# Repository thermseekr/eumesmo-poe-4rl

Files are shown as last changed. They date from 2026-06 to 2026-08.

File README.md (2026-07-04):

# eumesmo-poe-4rl
PoE powered ESP32 based board featuring 4 SPST NO relays. Ideal for access control, doors, isolated zones or for installing anywhere you need to click dry contacts near some equipment or appliance.

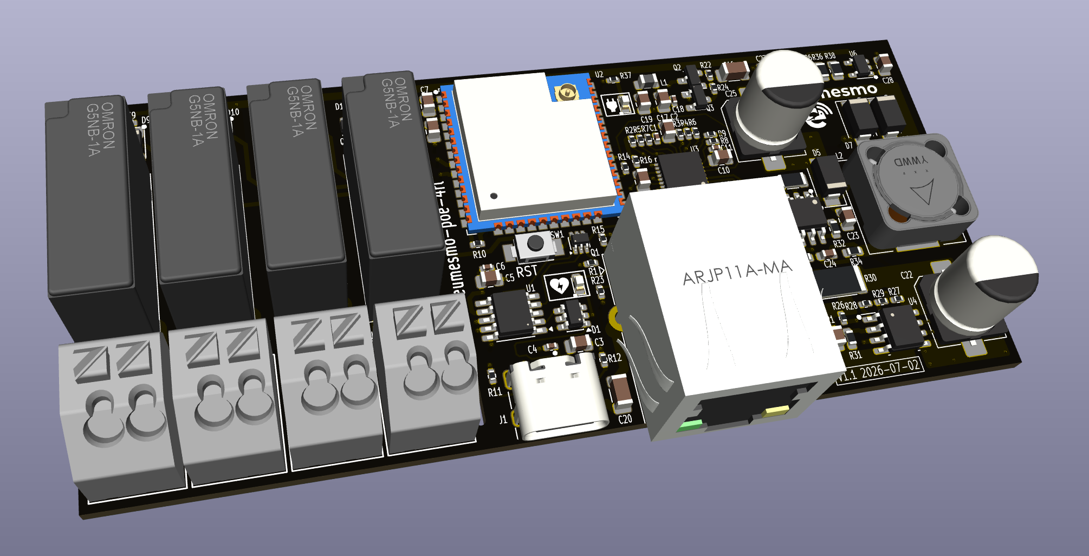
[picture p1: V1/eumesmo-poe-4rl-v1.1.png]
eumesmo-poe-4rl


## VERSION HISTORY

V1.1 - 2026/07/02 - Added CPU health LED.

V1.0 - 2026/06/16 - Initial release.

## LICENSE

This project is licensed under the [Creative Commons BY-NC 4.0 License](https://creativecommons.org/licenses/by-nc/4.0/).
Commercial use is not permitted without prior written consent. See the [LICENSE.txt](LICENSE.txt) file for details.

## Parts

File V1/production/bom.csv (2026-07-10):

Designator | Footprint | Quantity | Value | LCSC Part #
C1, C12, C15, C18, C4, C6, C8, C9 | 0402 | 8 | 100nF/50V | C307331
C10, C13, C3 | 0805 | 3 | 1uF/50V | C28323
C11 | 0402 | 1 | 470pF/50V | C1537
C14, C17, C19, C2, C28, C5, C7 | 0805 | 7 | 10uF/25V | C15850
C16, C27 | 1206 | 2 | 22uF/10V | C5672
C20 | 1206 | 1 | 1nF/2kV | C9196
C21, C23 | 0805 | 2 | 100nF/100V | C28233
C22 | CP_Elec_8x10.5 | 1 | 22uF/100V | C178570
C24 | 0603 | 1 | 12pF/50V | C38523
C25 | CP_Elec_8x10.5 | 1 | 470uF/16V | C96179
C26 | 0402 | 1 | 22pF/50V | C1555
D1 | SOT-23-6 | 1 | USBLC6-2SC6 | C7519
D10, D13, D14, D9 | D_SOD-123 | 4 | 1N4148 | C81598
D11, D12, D15, D16, D3, D8 | 0603 | 6 | WHITE/0603 | C2290
D2 | SOT-23-5 | 1 | ESDS314DBV | C1847859
D4 | D_SMA | 1 | SMAJ58A | C132936
D5 | D_SMA | 1 | SS510 | C65010
D6, D7 | D_SMA | 2 | SS34 | C8678
J1 | USB_C_Receptacle_GCT_USB4105-xx-A_16P_TopMnt_Horizontal | 1 | USB_C_Receptacle_USB2.0 | C2765186
J2 | RJ45_HanRun_HY931147C | 1 | RJ45 JACK | C91754
J3, J4, J5, J6 | TerminalBlock_Wago_250-202_1x02_P3.5mm_45Degree | 4 | 250-202 | C2765061
K1, K2, K3, K4 | Relay_SPST_Omron_G5NB-1A | 4 | G5NB-1A-E-DC5 | C48746
L1 | 0805 | 1 | 2A/600R | C139168
L2 | L_12x12mm_H6mm | 1 | 33uH/2,1A | C169386
L3 | L_3x3mm_H1.5mm | 1 | 2,2uH/1,5A | C370424
Q1 | SOT-363_SC-70-6 | 1 | UMH3N | C62892
Q2 | SOT-23 | 1 | WPM2015-3/TR | C558305
Q3 | SOT-23 | 1 | LMUN2211LT1G | C150229
Q4, Q5, Q6, Q7 | SOT-23 | 4 | MMBT2222A | C8512
R1, R10, R13, R16, R22, R29, R43, R44, R49, R50 | 0402 | 10 | 10k | C25744
R11, R12 | 0402 | 2 | 5,1k | C105872
R14 | 0402 | 1 | 33R | C25105
R15, R23, R25, R37 | 0402 | 4 | 330R | C25104
R17, R19, R20, R21 | 0402 | 4 | 49,9R | C25120
R18 | 0402 | 1 | 12,1k | C25852
R2 | 0402 | 1 | 1.5k | C25867
R24, R39, R40, R41, R42, R45, R46, R47, R48 | 0402 | 9 | 1k | C11702
R26 | 0402 | 1 | 30,1k | C138009
R27 | 0402 | 1 | 130k | C93946
R28 | 0402 | 1 | 180k | C138046
R3, R4, R5, R6, R7, R8, R9 | 0402 | 7 | 2.2k | C25879
R30 | 2512 | 1 | 4,7k/1W | C878291
R31 | 0603 | 1 | 4,42k/100mW | C482858
R32 | 0603 | 1 | 5,1R/100mW | C25197
R33 | 1206 | 1 | 30mR/250mW | C473665
R34 | 0603 | 1 | 300k/100mW | C23024
R35 | 0603 | 1 | 52,3k/100mW | C23198
R36 | 0805 | 1 | 100k/0,125W | C149504
R38 | 0805 | 1 | 22,1k/0,125W | C17552
SW1 | SW_SPST_Xunpu_TS1088AR02016 | 1 | RESET | C720477
U1 | SSOP-10-1EP_3.9x4.9mm_P1mm_EP2.1x3.3mm | 1 | CH340K | C968586
U2 | ESP32-WROOM-32U | 1 | ESP32-WROOM-32UE-N16 | C701346
U3 | QFN-32-1EP_5x5mm_P0.5mm_EP3.3x3.3mm_ThermalVias | 1 | LAN8710A | C46185
U4 | SOIC-8-1EP_3.9x4.9mm_P1.27mm_EP2.95x4.9mm_Mask2.71x3.4mm_ThermalVias | 1 | TPS2376DDAR-H | C544899
U5 | SOIC-8-1EP_3.9x4.9mm_P1.27mm_EP2.41x3.81mm_ThermalVias | 1 | TX4138 | C329267
U6 | SOT-23-5_Shorter_Pins | 1 | SY8089A1AAC | C479074

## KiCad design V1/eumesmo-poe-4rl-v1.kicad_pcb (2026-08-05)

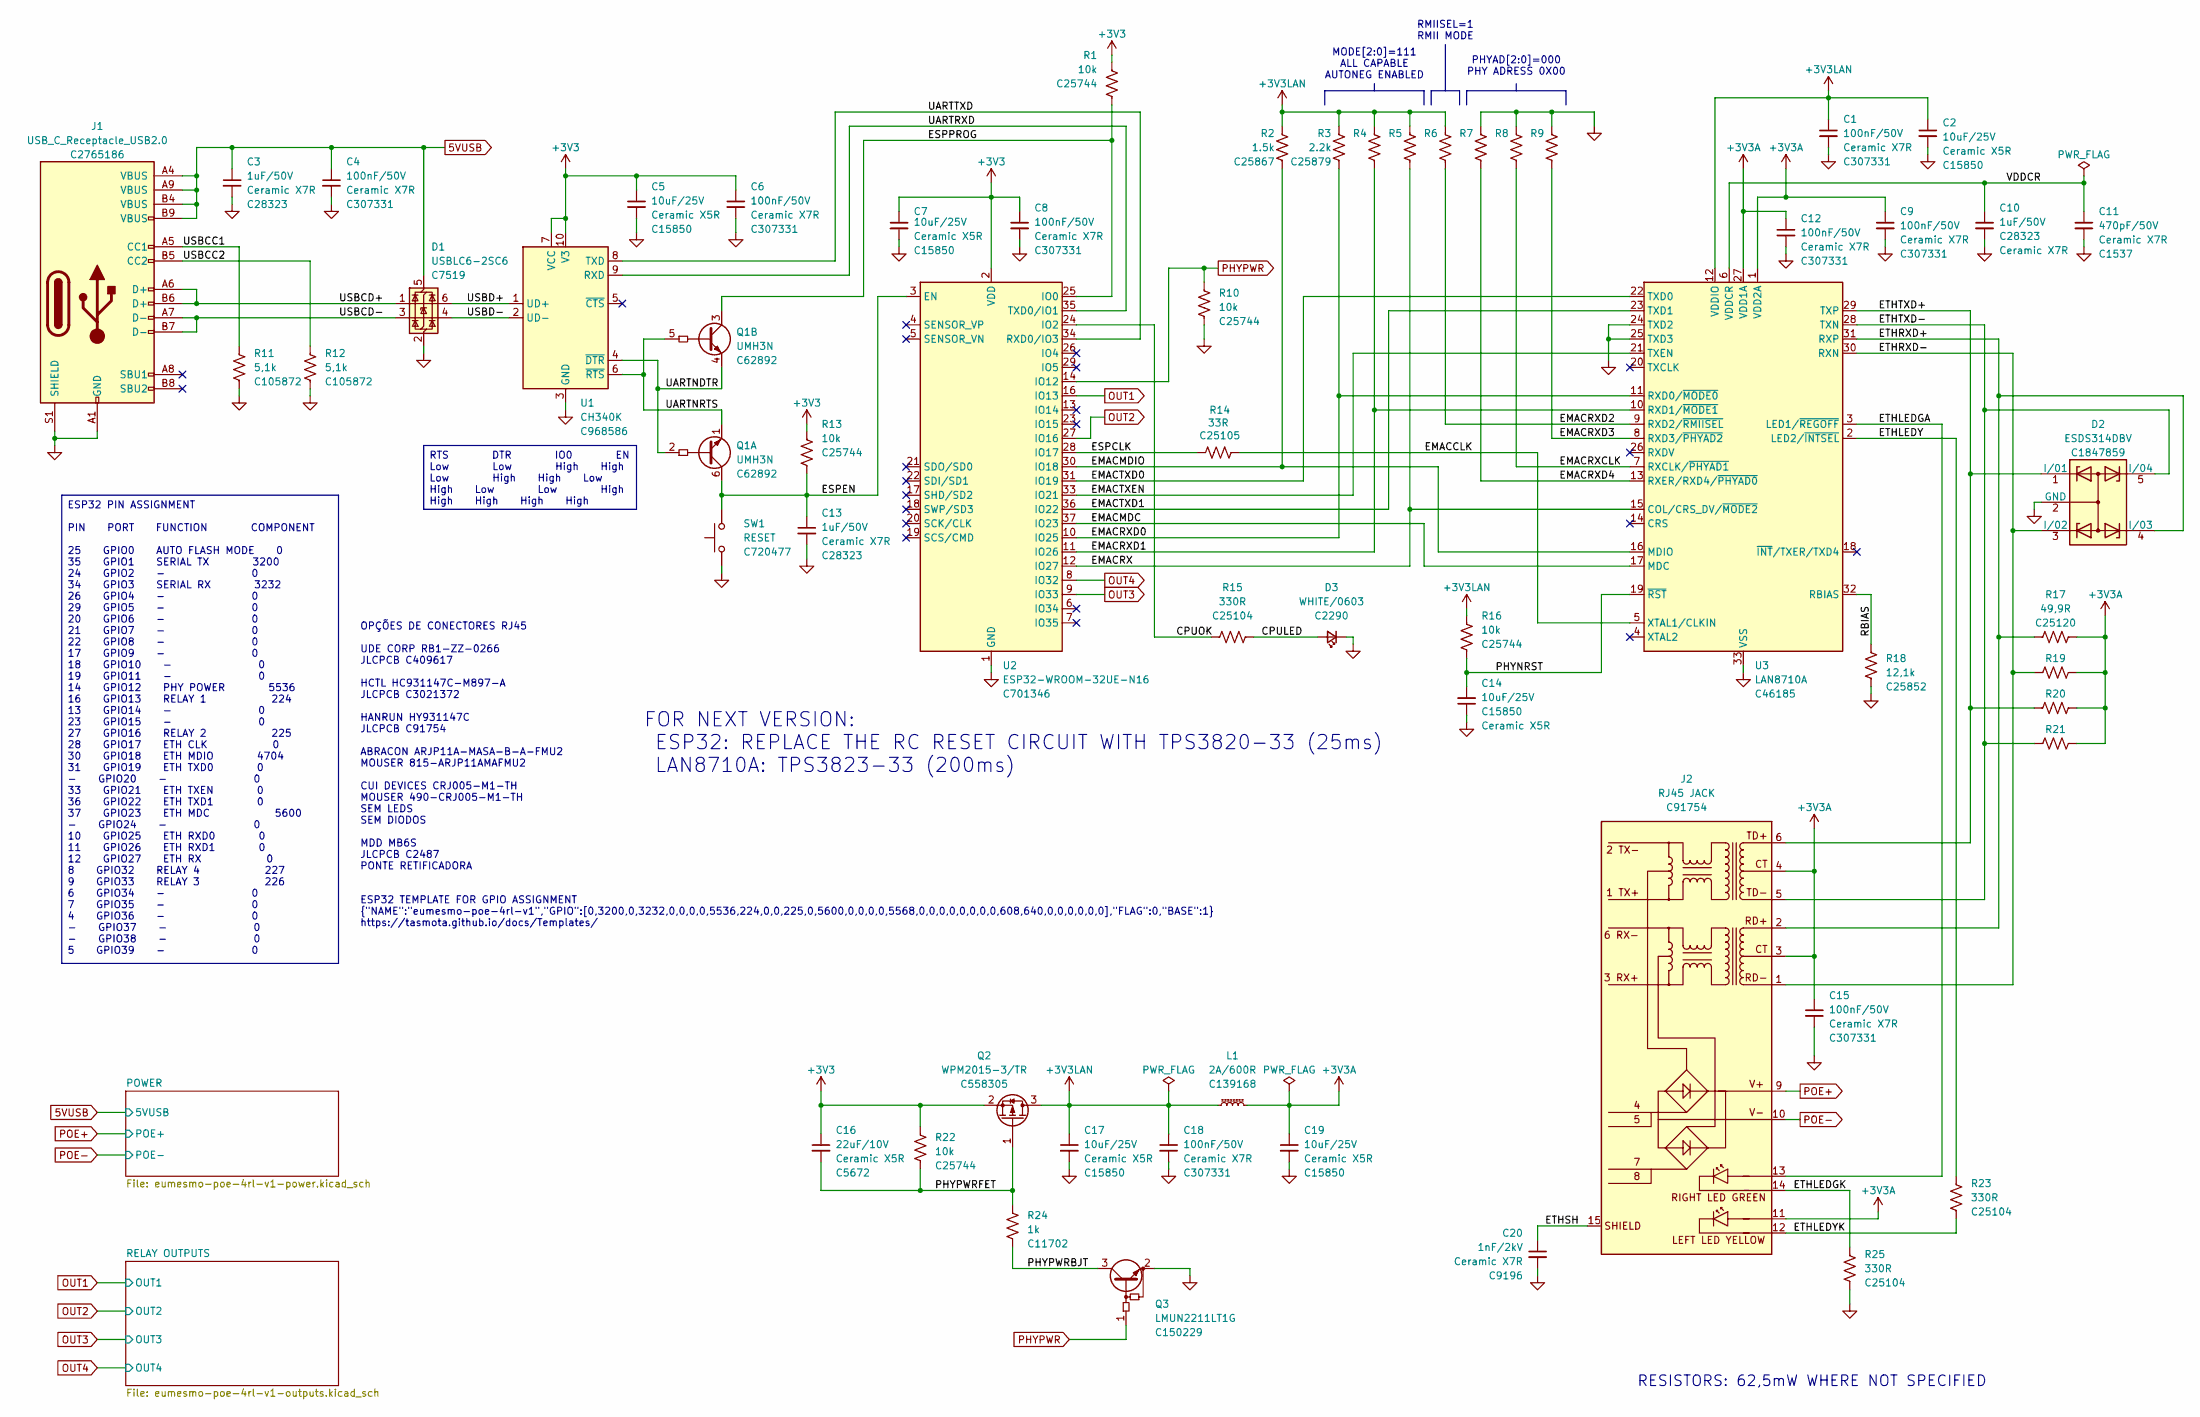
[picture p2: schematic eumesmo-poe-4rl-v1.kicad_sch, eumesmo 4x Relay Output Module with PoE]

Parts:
C1, C4, C6, C8, C9, C12, C15, C18: 100nF/50V; C_0402_1005Metric; Mfr PN CL05B104KB54PNC; JLCPCB BOM 1
C2, C7, C14, C17, C19: 10uF/25V; C_0805_2012Metric; Mfr PN CL21A106KAYNNNE; JLCPCB BOM 1
C3, C10, C13: 1uF/50V; C_0805_2012Metric; Mfr PN CL21B105KBFNNNE; JLCPCB BOM 1
C5: 10uF/25V; C_0805_2012Metric; Mfr PN CL21A106KAYNNNE; LCSC Part # C15850
C11: 470pF/50V; C_0402_1005Metric; Mfr PN 0402B471K500NT; JLCPCB BOM 1
C16: 22uF/10V; C_1206_3216Metric; Mfr PN CL31A226KPHNNNE; JLCPCB BOM 1
C20: 1nF/2kV; C_1206_3216Metric; Mfr PN 1206B102K202NT; JLCPCB BOM 1
D1: USBLC6-2SC6; SOT-23-6; Mfr PN USBLC6-2SC6; JLCPCB BOM 1
D2: ESDS314DBV; SOT-23-5; Mfr PN ESDS314DBVR; JLCPCB BOM 1
D3: WHITE/0603; LED_0603_1608Metric; Mfr PN KT-0603W; LCSC Part # C2290
J1: USB_C_Receptacle_USB2.0; USB_C_Receptacle_GCT_USB4105-xx-A_16P_TopMnt_Horizontal; Mfr PN TYPE-C 16PIN 2MD(073); JLCPCB BOM 1
J2: RJ45 JACK; RJ45_HanRun_HY931147C; Mfr PN HY931147C; JLCPCB BOM 1
L1: 2A/600R; L_0805_2012Metric; Mfr PN CBM201209U601T; JLCPCB BOM 1
Q1: UMH3N; SOT-363_SC-70-6; Mfr PN UMH3N; JLCPCB BOM 1
Q2: WPM2015-3/TR; SOT-23; Mfr PN WPM2015-3/TR; JLCPCB BOM 1
Q3: LMUN2211LT1G; SOT-23; Mfr PN MMUN2211LT3G; LCSC Part # C150229
R1, R10, R13, R16, R22: 10k; R_0402_1005Metric; Mfr PN 0402WGF1002TCE; LCSC Part # C25744
R2: 1.5k; R_0402_1005Metric; Mfr PN 0402WGF1501TCE; LCSC Part # C25867
R3, R4, R5, R6, R7, R8, R9: 2.2k; R_0402_1005Metric; Mfr PN 0402WGF2201TCE; LCSC Part # C25879
R11, R12: 5,1k; R_0402_1005Metric; Mfr PN RC0402FR-075K1L; JLCPCB BOM 1
R14: 33R; R_0402_1005Metric; Mfr PN 0402WGF330JTCE; JLCPCB BOM 1
R15, R23, R25: 330R; R_0402_1005Metric; Mfr PN 0402WGF3300TCE; LCSC Part # C25104
R17, R19, R20, R21: 49,9R; R_0402_1005Metric; Mfr PN 0402WGF499JTCE; JLCPCB BOM 1
R18: 12,1k; R_0402_1005Metric; Mfr PN 0402WGF1212TCE; JLCPCB BOM 1
R24: 1k; R_0402_1005Metric; Mfr PN 0402WGF1001TCE; LCSC Part # C11702
SW1: RESET; SW_SPST_Xunpu_TS1088AR02016; Mfr PN TS-1088-AR02016; JLCPCB BOM 1
U1: CH340K; SSOP-10-1EP_3.9x4.9mm_P1mm_EP2.1x3.3mm; Mfr PN CH340K; JLCPCB BOM 1
U2: ESP32-WROOM-32UE-N16; ESP32-WROOM-32U; Mfr PN ESP32-WROOM-32UE-N16; JLCPCB BOM 1
U3: LAN8710A; QFN-32-1EP_5x5mm_P0.5mm_EP3.3x3.3mm_ThermalVias; Mfr PN LAN8710A-EZC-TR; JLCPCB BOM 1

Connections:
5VUSB: C3.1, C4.1, D1.5 (VBUS), J1.A4 (VBUS), J1.A9 (VBUS), J1.B4 (VBUS), J1.B9 (VBUS); also elsewhere on the board
+3V3: C5.1, C6.1, C7.1, C8.1, C16.1, Q2.2 (S), R1.1, R13.1, R22.1, U1.7 (VCC), U1.10 (V3), U2.2 (VDD); also elsewhere on the board
+3V3A: C9.1, C12.1, C15.1, C19.1, J2.3 (CT), J2.4 (CT), J2.11 (LLED+), L1.2, R17.2, R19.2, R20.2, R21.2, U3.1 (VDD2A), U3.27 (VDD1A)
+3V3LAN: C1.1, C2.1, C17.1, C18.1, L1.1, Q2.3 (D), R2.1, R3.1, R4.1, R5.1, R6.1, R16.2, U3.12 (VDDIO)
/CPULED: D3.2 (A), R15.2
/CPUOK: R15.1, U2.24 (IO2)
/EMACCLK: R14.2, U3.5 (XTAL1/CLKIN)
/EMACMDC: U2.37 (IO23), U3.17 (MDC)
/EMACMDIO: R2.2, U2.30 (IO18), U3.16 (MDIO)
/EMACRX: R5.2, U2.12 (IO27), U3.15 (COL/CRS_DV/~MODE2)
/EMACRXCLK: R8.2, U3.7 (RXCLK/~PHYAD1)
/EMACRXD0: R3.2, U2.10 (IO25), U3.11 (RXD0/~MODE0)
/EMACRXD1: R4.2, U2.11 (IO26), U3.10 (RXD1/~MODE1)
/EMACRXD2: R6.2, U3.9 (RXD2/~RMIISEL)
/EMACRXD3: R9.2, U3.8 (RXD3/~PHYAD2)
/EMACRXD4: R7.2, U3.13 (RXER/RXD4/~PHYAD0)
/EMACTXD0: U2.31 (IO19), U3.22 (TXD0)
/EMACTXD1: U2.36 (IO22), U3.23 (TXD1)
/EMACTXEN: U2.33 (IO21), U3.21 (TXEN)
/ESPCLK: R14.1, U2.28 (IO17)
/ESPEN: C13.1, Q1.6 (C1), R13.2, SW1.2, U2.3 (EN)
/ESPPROG: Q1.3 (C2), R1.2, U2.25 (IO0)
/ETHLEDGA: J2.13 (RLED+), U3.3 (LED1/~REGOFF)
/ETHLEDGK: J2.14 (RLED-), R25.2
/ETHLEDY: R23.2, U3.2 (LED2/~INTSEL)
/ETHLEDYK: J2.12 (LLED-), R23.1
/ETHRXD+: D2.4 (I/03), J2.2 (RD+), R17.1, U3.31 (RXP)
/ETHRXD-: D2.3 (I/02), J2.1 (RD-), R19.1, U3.30 (RXN)
/ETHSH: C20.1, J2.15 (SHIELD)
/ETHTXD+: D2.1 (I/01), J2.6 (TD+), R20.1, U3.29 (TXP)
/ETHTXD-: D2.5 (I/04), J2.5 (TD-), R21.1, U3.28 (TXN)
/PHYNRST: C14.2, R16.1, U3.19 (~RST)
/PHYPWRBJT: Q3.3 (C), R24.2
/PHYPWRFET: C16.2, Q2.1 (G), R22.2, R24.1
/RBIAS: R18.1, U3.32 (RBIAS)
/UARTNDTR: Q1.2 (B1), Q1.4 (E2), U1.4 (~DTR)
/UARTNRTS: Q1.1 (E1), Q1.5 (B2), U1.6 (~RTS)
/UARTRXD: U1.9 (RXD), U2.35 (TXD0/IO1)
/UARTTXD: U1.8 (TXD), U2.34 (RXD0/IO3)
/USBCC1: J1.A5 (CC1), R11.1
/USBCC2: J1.B5 (CC2), R12.1
/USBCD+: D1.1 (I/O1), J1.A6 (D+), J1.B6 (D+)
/USBCD-: D1.3 (I/O2), J1.A7 (D-), J1.B7 (D-)
/USBD+: D1.6 (I/O1), U1.1 (UD+)
/USBD-: D1.4 (I/O2), U1.2 (UD-)
/VDDCR: C10.1, C11.1, U3.6 (VDDCR)
GND: C1.2, C2.2, C3.2, C4.2, C5.2, C6.2, C7.2, C8.2, C9.2, C10.2, C11.2, C12.2, C13.2, C14.1, C15.2, C17.2, C18.2, C19.2, C20.2, D1.2 (GND), D2.2 (GND), D3.1 (K), J1.A1 (GND), J1.A12 (GND), J1.B1 (GND), J1.B12 (GND), J1.S1 (SHIELD), Q3.2 (E), R7.1, R8.1, R9.1, R10.1, R11.2, R12.2, R18.2, R25.1, SW1.1, U1.3 (GND), U1.11 (GND), U2.1 (GND), U2.15 (GND), U2.38 (GND), U2.39 (GND), U3.24 (TXD2), U3.25 (TXD3), U3.33 (VSS); also elsewhere on the board
OUT1: U2.16 (IO13); also elsewhere on the board
OUT2: U2.27 (IO16); also elsewhere on the board
OUT3: U2.9 (IO33); also elsewhere on the board
OUT4: U2.8 (IO32); also elsewhere on the board
PHYPWR: Q3.1 (B), R10.2, U2.14 (IO12)
POE+: J2.9 (V+); also elsewhere on the board
POE-: J2.10 (V-); also elsewhere on the board

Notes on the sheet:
RMIISEL=1 RMII MODE
PHYAD[2:0]=000 PHY ADRESS 0X00
OPÇÕES DE CONECTORES RJ45 UDE CORP RB1-ZZ-0266 JLCPCB C409617 HCTL HC931147C-M897-A JLCPCB C3021372 HANRUN HY931147C JLCPCB C91754 ABRACON ARJP11A-MASA-B-A-FMU2 MOUSER 815-ARJP11AMAFMU2 CUI DEVICES CRJ005-M1-TH MOUSER 490-CRJ005-M1-TH SEM LEDS SEM DIODOS MDD MB6S JLCPCB C2487 PONTE RETIFICADORA
ESP32 TEMPLATE FOR GPIO ASSIGNMENT {"NAME":"eumesmo-poe-4rl-v1","GPIO":[0,3200,0,3232,0,0,0,0,5536,224,0,0,225,0,5600,0,0,0,0,5568,0,0,0,0,0,0,0,0,608,640,0,0,0,0,0,0],"FLAG":0,"BASE":1} https://tasmota.github.io/docs/Templates/
RESISTORS: 62,5mW WHERE NOT SPECIFIED
MODE[2:0]=111 ALL CAPABLE AUTONEG ENABLED
FOR NEXT VERSION: ESP32: REPLACE THE RC RESET CIRCUIT WITH TPS3820-33 (25ms) LAN8710A: TPS3823-33 (200ms)
ESP32 PIN ASSIGNMENT PIN PORT FUNCTION COMPONENT 25 GPIO0 AUTO FLASH MODE 0 35 GPIO1 SERIAL TX 3200 24 GPIO2 - 0 34 GPIO3 SERIAL RX 3232 26 GPIO4 - 0 29 GPIO5 - 0 20 GPIO6 - 0 21 GPIO7 - 0 22 GPIO8 - 0 17 GPIO9 - 0 18 GPIO10 - 0 19 GPIO11 - 0 14 GPIO12 PHY POWER 5536 16 GPIO13 RELAY 1 224 13 GPIO14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
RTS DTR IO0 EN Low Low High High Low High High Low High Low Low High High High High High

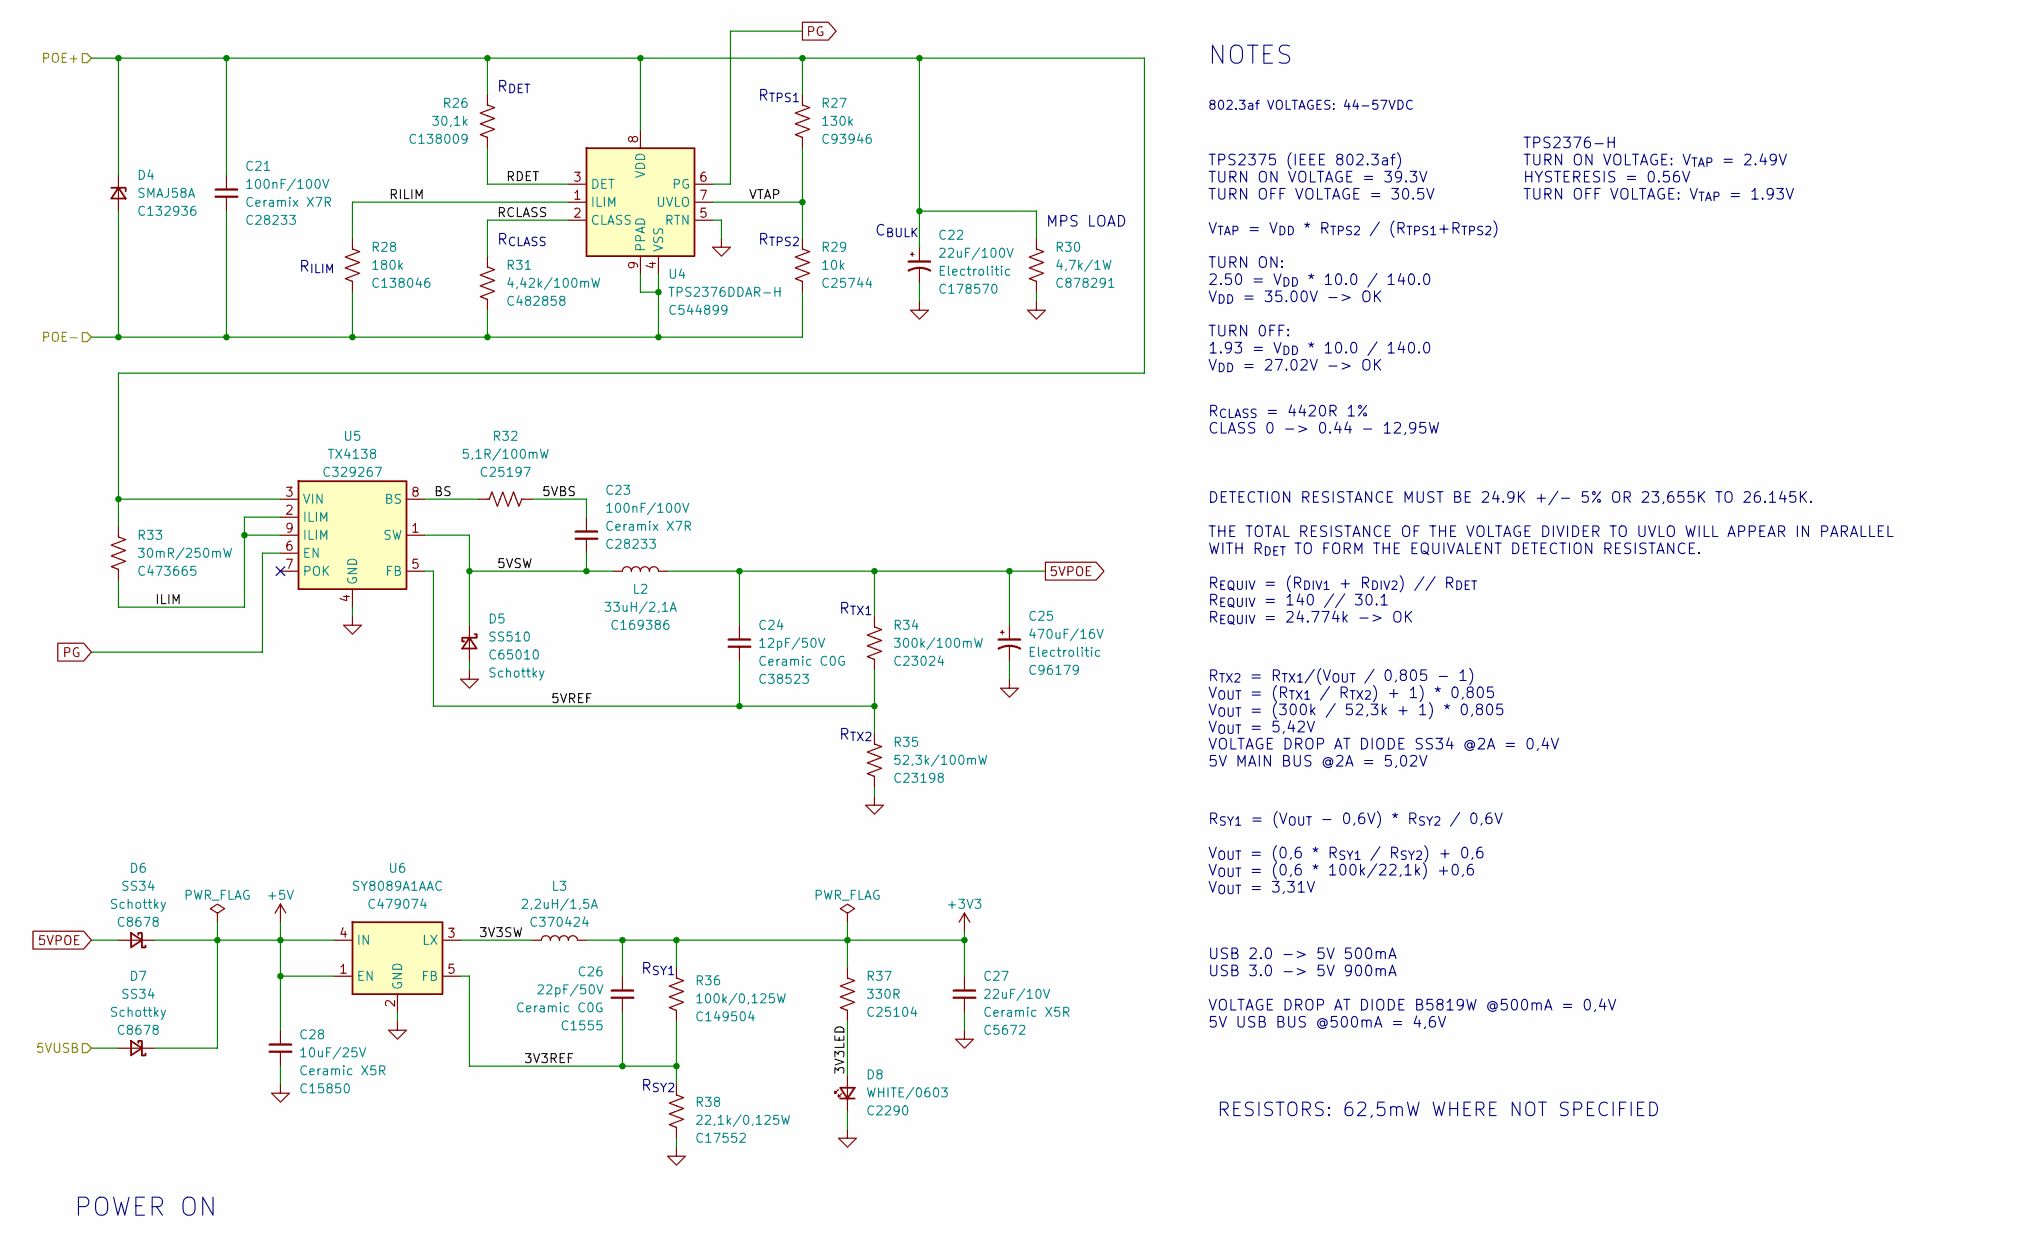
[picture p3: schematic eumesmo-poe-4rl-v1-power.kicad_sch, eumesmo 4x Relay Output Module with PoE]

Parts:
C21: 100nF/100V; C_0805_2012Metric; Mfr PN CL21B104KCFNNNE; JLCPCB BOM 1
C22: 22uF/100V; CP_Elec_8x10.5; Mfr PN EEEFK2A220P; LCSC Part # C178570
C23: 100nF/100V; C_0805_2012Metric; Mfr PN CL21B104KCFNNNE; LCSC Part # C28233
C24: 12pF/50V; C_0603_1608Metric; Mfr PN CL10C120JB8NNNC; JLCPCB BOM 1
C25: 470uF/16V; CP_Elec_8x10.5; Mfr PN CS1C471M-CRF10; JLCPCB BOM 1
C26: 22pF/50V; C_0402_1005Metric; Mfr PN 0402CG220J500NT; JLCPCB BOM 1
C27: 22uF/10V; C_1206_3216Metric; Mfr PN CL31A226KPHNNNE; JLCPCB BOM 1
C28: 10uF/25V; C_0805_2012Metric; Mfr PN CL21A106KAYNNNE; JLCPCB BOM 1
D4: SMAJ58A; D_SMA; Mfr PN SMAJ58A-TR; JLCPCB BOM 1
D5: SS510; D_SMA; Mfr PN SS510; JLCPCB BOM 1
D6, D7: SS34; D_SMA; Mfr PN SS34; JLCPCB BOM 1
D8: WHITE/0603; LED_0603_1608Metric; Mfr PN KT-0603W; LCSC Part # C2290
L2: 33uH/2,1A; L_12x12mm_H6mm; Mfr PN SWRB1205S-330MT; JLCPCB BOM 1
L3: 2,2uH/1,5A; L_3x3mm_H1.5mm; Mfr PN SPH3015H2R2MT; JLCPCB BOM 1
R26: 30,1k; R_0402_1005Metric; Mfr PN RC0402FR-0730K1L; JLCPCB BOM 1
R27: 130k; R_0402_1005Metric; Mfr PN RC0402FR-07130KL; JLCPCB BOM 1
R28: 180k; R_0402_1005Metric; Mfr PN RC0402FR-07180KL; JLCPCB BOM 1
R29: 10k; R_0402_1005Metric; Mfr PN 0402WGF1002TCE; JLCPCB BOM 1
R30: 4,7k/1W; R_2512_6332Metric; Mfr PN RC2512JK-074K7L; JLCPCB BOM 1
R31: 4,42k/100mW; R_0603_1608Metric; Mfr PN RC0603FR-074K42L; JLCPCB BOM 1
R32: 5,1R/100mW; R_0603_1608Metric; Mfr PN 0603WAF510KT5E; LCSC Part # C25197
R33: 30mR/250mW; R_1206_3216Metric; Mfr PN 1206W3F300MT5E; LCSC Part # C473665
R34: 300k/100mW; R_0603_1608Metric; Mfr PN 0603WAF3003T5E; JLCPCB BOM 1
R35: 52,3k/100mW; R_0603_1608Metric; Mfr PN 0603WAF5232T5E; JLCPCB BOM 1
R36: 100k/0,125W; R_0805_2012Metric; Mfr PN 0805W8F1003T5E; JLCPCB BOM 1
R37: 330R; R_0402_1005Metric; Mfr PN 0402WGF3300TCE; LCSC Part # C25104
R38: 22,1k/0,125W; R_0805_2012Metric; Mfr PN 0805W8F2212T5E; JLCPCB BOM 1
U4: TPS2376DDAR-H; SOIC-8-1EP_3.9x4.9mm_P1.27mm_EP2.95x4.9mm_Mask2.71x3.4mm_Th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; Mfr PN TPS2376DDAR-H; JLCPCB BOM 1
U5: TX4138; SOIC-8-1EP_3.9x4.9mm_P1.27mm_EP2.41x3.81mm_ThermalVias; Mfr PN TX4138; JLCPCB BOM 1
U6: SY8089A1AAC; SOT-23-5_Shorter_Pins; Mfr PN SY8089A1AAC; JLCPCB BOM 1

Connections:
5VPOE: C24.1, C25.1, D6.2 (A), L2.2, R34.1
5VUSB: D7.2 (A); also elsewhere on the board
+3V3: C26.1, C27.1, L3.2, R36.1, R37.1; also elsewhere on the board
+5V: C28.1, D6.1 (K), D7.1 (K), U6.1 (EN), U6.4 (IN); also elsewhere on the board
/POWER/3V3LED: D8.2 (A), R37.2
/POWER/3V3REF: C26.2, R36.2, R38.1, U6.5 (FB)
/POWER/3V3SW: L3.1, U6.3 (LX)
/POWER/5VBS: C23.1, R32.1
/POWER/5VREF: C24.2, R34.2, R35.1, U5.5 (FB)
/POWER/5VSW: C23.2, D5.1 (K), L2.1, U5.1 (SW)
/POWER/BS: R32.2, U5.8 (BS)
/POWER/ILIM: R33.2, U5.2 (ILIM), U5.9 (ILIM)
/POWER/RCLASS: R31.1, U4.2 (CLASS)
/POWER/RDET: R26.2, U4.3 (DET)
/POWER/RILIM: R28.1, U4.1 (ILIM)
/POWER/VTAP: R27.2, R29.1, U4.7 (UVLO)
GND: C22.2, C25.2, C27.2, C28.2, D5.2 (A), D8.1 (K), R30.2, R35.2, R38.2, U4.5 (RTN), U5.4 (GND), U6.2 (GND); also elsewhere on the board
PG: U4.6 (PG), U5.6 (EN)
POE+: C21.1, C22.1, D4.1 (K), R26.1, R27.1, R30.1, R33.1, U4.8 (VDD), U5.3 (VIN); also elsewhere on the board
POE-: C21.2, D4.2 (A), R28.2, R29.2, R31.2, U4.4 (VSS), U4.9 (PPAD); also elsewhere on the board

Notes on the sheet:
R_{TPS1}
R_{TX2}
DETECTION RESISTANCE MUST BE 24.9K +/- 5% OR 23,655K TO 26.145K. THE TOTAL RESISTANCE OF THE VOLTAGE DIVIDER TO UVLO WILL APPEAR IN PARALLEL WITH R_{DET} TO FORM THE EQUIVALENT DETECTION RESISTANCE. R_{EQUIV} = (R_{DIV1} + R_{DIV2}) // R_{DET} R_{EQUIV} = 140 // 30.1 R_{EQUIV} = 24.774k -> OK
R_{SY2}
RESISTORS: 62,5mW WHERE NOT SPECIFIED
POWER ON
R_{CLASS} = 4420R 1% CLASS 0 -> 0.44 - 12,95W
R_{SY1}
R_{CLASS}
R_{TX2} = R_{TX1}/(V_{OUT} / 0,805 - 1) V_{OUT} = (R_{TX1} / R_{TX2}) + 1) * 0,805 V_{OUT} = (300k / 52,3k + 1) * 0,805 V_{OUT} = 5,42V VOLTAGE DROP AT DIODE SS34 @2A = 0,4V 5V MAIN BUS @2A = 5,02V
C_{BULK}
R_{ILIM}
USB 2.0 -> 5V 500mA USB 3.0 -> 5V 900mA VOLTAGE DROP AT DIODE B5819W @500mA = 0,4V 5V USB BUS @500mA = 4,6V
TPS2375 (IEEE 802.3af) TURN ON VOLTAGE = 39.3V TURN OFF VOLTAGE = 30.5V
TPS2376-H TURN ON VOLTAGE: V_{TAP} = 2.49V HYSTERESIS = 0.56V TURN OFF VOLTAGE: V_{TAP} = 1.93V
R_{SY1} = (V_{OUT} - 0,6V) * R_{SY2} / 0,6V V_{OUT} = (0,6 * R_{SY1} / R_{SY2}) + 0,6 V_{OUT} = (0,6 * 100k/22,1k) +0,6 V_{OUT} = 3,31V
R_{TPS2}
R_{TX1}
NOTES
MPS LOAD
R_{DET}
802.3af VOLTAGES: 44-57VDC
V_{TAP} = V_{DD} * R_{TPS2} / (R_{TPS1}+R_{TPS2}) TURN ON: 2.50 = V_{DD} * 10.0 / 140.0 V_{DD} = 35.00V -> OK TURN 0FF: 1.93 = V_{DD} * 10.0 / 140.0 V_{DD} = 27.02V -> OK

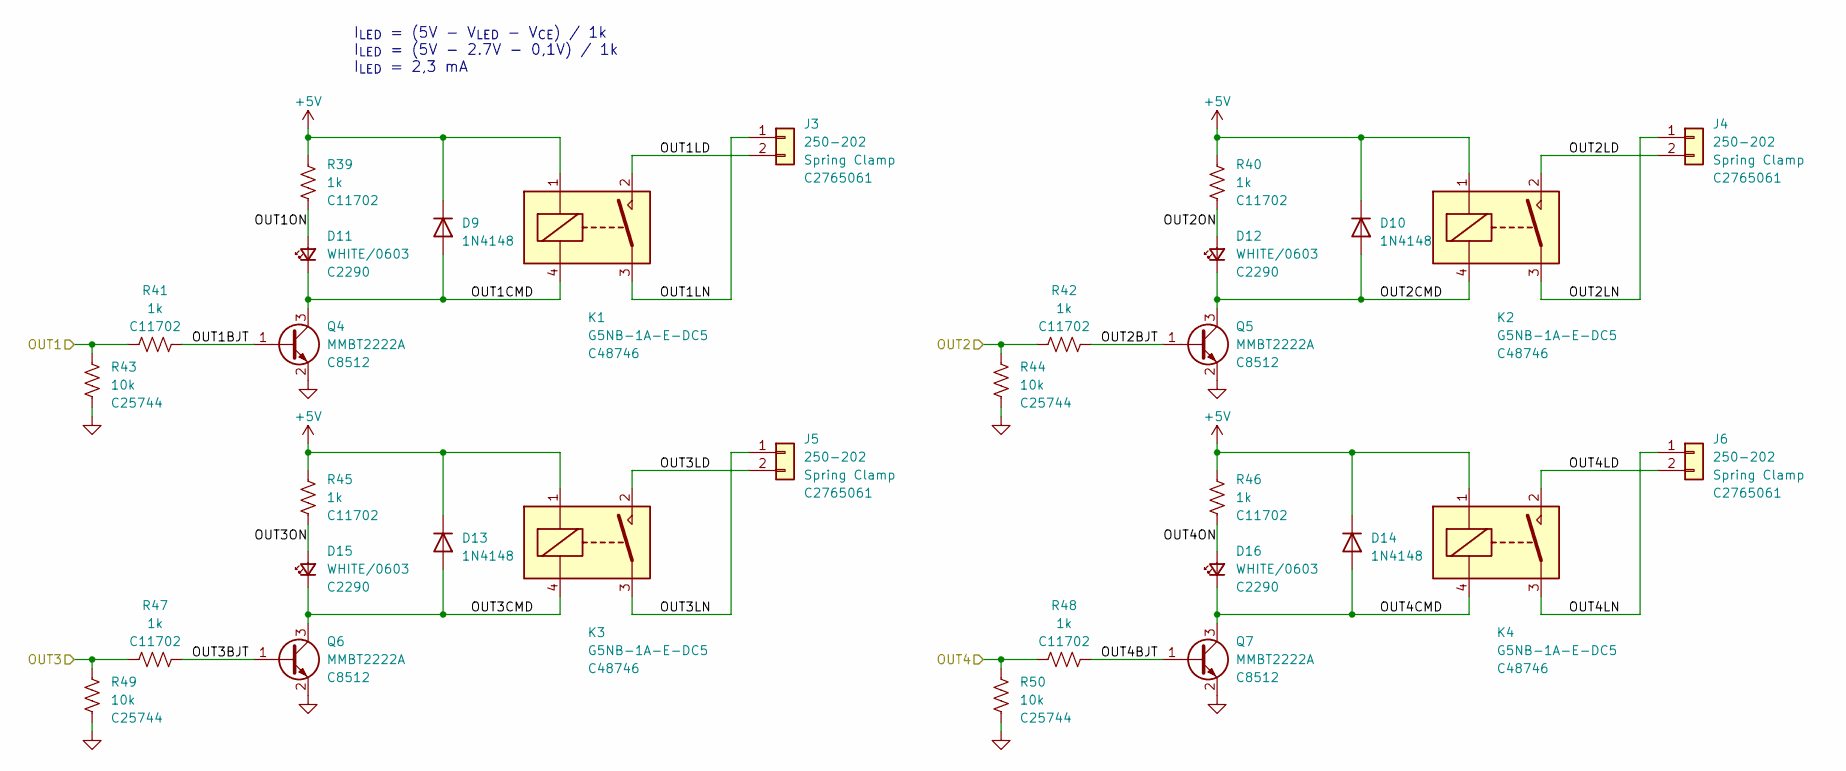
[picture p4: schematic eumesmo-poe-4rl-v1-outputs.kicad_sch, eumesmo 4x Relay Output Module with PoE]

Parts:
D9, D10, D13, D14: 1N4148; D_SOD-123; Mfr PN 1N4148W; JLCPCB BOM 1
D11, D12, D15, D16: WHITE/0603; LED_0603_1608Metric; Mfr PN KT-0603W; LCSC Part # C2290
J3, J4, J5, J6: 250-202; TerminalBlock_Wago_250-202_1x02_P3.5mm_45Degree; Mfr PN 250-202; JLCPCB BOM 1
K1, K2, K3, K4: G5NB-1A-E-DC5; Relay_SPST_Omron_G5NB-1A; Mfr PN G5NB-1A-E-DC5; JLCPCB BOM 1
Q4, Q5, Q6, Q7: MMBT2222A; SOT-23; Mfr PN MMBT2222A; JLCPCB BOM 1
R39, R40, R41, R42, R45, R46, R47, R48: 1k; R_0402_1005Metric; Mfr PN 0402WGF1001TCE; LCSC Part # C11702
R43, R44, R49, R50: 10k; R_0402_1005Metric; Mfr PN 0402WGF1002TCE; LCSC Part # C25744

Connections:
+5V: D9.1 (K), D10.1 (K), D13.1 (K), D14.1 (K), K1.1, K2.1, K3.1, K4.1, R39.1, R40.1, R45.1, R46.1; also elsewhere on the board
/RELAY OUTPUTS/OUT1BJT: Q4.1 (B), R41.1
/RELAY OUTPUTS/OUT1CMD: D9.2 (A), D11.1 (K), K1.4, Q4.3 (C)
/RELAY OUTPUTS/OUT1LD: J3.2, K1.2
/RELAY OUTPUTS/OUT1LN: J3.1, K1.3
/RELAY OUTPUTS/OUT1ON: D11.2 (A), R39.2
/RELAY OUTPUTS/OUT2BJT: Q5.1 (B), R42.1
/RELAY OUTPUTS/OUT2CMD: D10.2 (A), D12.1 (K), K2.4, Q5.3 (C)
/RELAY OUTPUTS/OUT2LD: J4.2, K2.2
/RELAY OUTPUTS/OUT2LN: J4.1, K2.3
/RELAY OUTPUTS/OUT2ON: D12.2 (A), R40.2
/RELAY OUTPUTS/OUT3BJT: Q6.1 (B), R47.1
/RELAY OUTPUTS/OUT3CMD: D13.2 (A), D15.1 (K), K3.4, Q6.3 (C)
/RELAY OUTPUTS/OUT3LD: J5.2, K3.2
/RELAY OUTPUTS/OUT3LN: J5.1, K3.3
/RELAY OUTPUTS/OUT3ON: D15.2 (A), R45.2
/RELAY OUTPUTS/OUT4BJT: Q7.1 (B), R48.1
/RELAY OUTPUTS/OUT4CMD: D14.2 (A), D16.1 (K), K4.4, Q7.3 (C)
/RELAY OUTPUTS/OUT4LD: J6.2, K4.2
/RELAY OUTPUTS/OUT4LN: J6.1, K4.3
/RELAY OUTPUTS/OUT4ON: D16.2 (A), R46.2
GND: Q4.2 (E), Q5.2 (E), Q6.2 (E), Q7.2 (E), R43.2, R44.2, R49.2, R50.2; also elsewhere on the board
OUT1: R41.2, R43.1; also elsewhere on the board
OUT2: R42.2, R44.1; also elsewhere on the board
OUT3: R47.2, R49.1; also elsewhere on the board
OUT4: R48.2, R50.1; also elsewhere on the board

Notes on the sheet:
I_{LED} = (5V - V_{LED} - V_{CE}) / 1k I_{LED} = (5V - 2.7V - 0,1V) / 1k I_{LED} = 2,3 mA

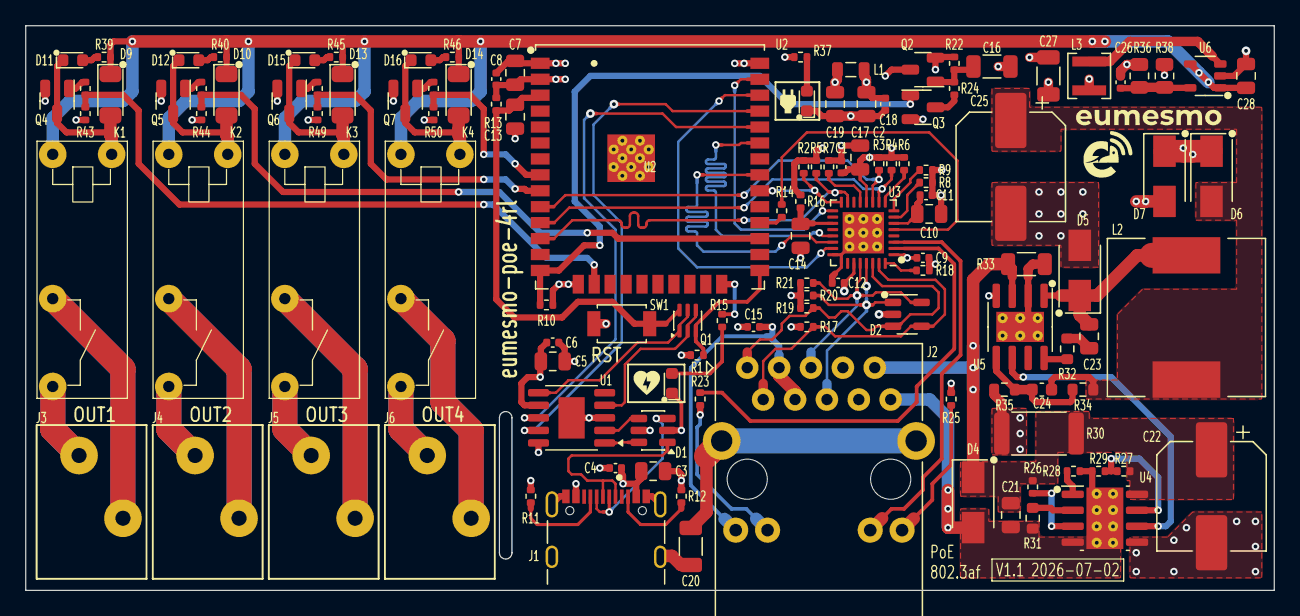
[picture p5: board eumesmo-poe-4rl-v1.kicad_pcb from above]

Board: 4 copper layers, 99.5 x 45.0 mm, 121 parts (0 on the bottom side), 89 nets.

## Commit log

2026-06-10 Adapting the schematics from 2 to 4 outputs
    [esp-poe-4rl-V1-power.kicad_sch, esp-poe-4rl-V1.kicad_pcb, esp-poe-4rl-V1.kicad_sch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]
2026-06-12 Under development.
    [esp-poe-4rl-V1.kicad_pcb, esp-poe-4rl-V1.kicad_sch, esp-poe-4rl-v1-outputs.kicad_sch]
2026-06-15 Adjusting traces width.
    [esp-poe-4rl-V1-power.kicad_sch, esp-poe-4rl-V1.kicad_pcb, esp-poe-4rl-v1-outputs.kicad_sch]
2026-06-16 Renamed all files to align with eumesmo branding.
    [eumesmo-poe-4rl-v1-outputs.kicad_sch, eumesmo-poe-4rl-v1-power.kicad_sch, eumesmo-poe-4rl-v1.kicad_pcb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]
2026-06-16 Rerouted TX/RX pairs between magjack and PHY.
    [bom.csv, designators.csv, eumesmo-poe-4rl-v1.kicad_pcb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]
2026-06-17 Widened pads at tracks and vias.
    [bom.csv, eumesmo-poe-4rl-v1.kicad_pcb, positions.csv]
2026-06-17 Release V1.0.0
    [eumesmo-poe-4rl-v1-outputs.kicad_sch, eumesmo-poe-4rl-v1-power.kicad_sch, eumesmo-poe-4rl-v1.kicad_pcb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]
2026-06-30 Added CPU health LED
    [bom.csv, designators.csv, eumesmo-poe-4rl-v1-outputs.kicad_sch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]
2026-07-10 Adjusted components according to availability in JLCPCB.
    [bom.csv, eumesmo-poe-4rl-v1-outputs.kicad_sch, eumesmo-poe-4rl-v1-power.kicad_sch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]
2026-07-10 Adjusted the footprint for the reset switch.
    [eumesmo-poe-4rl-v1.kicad_pcb]
2026-08-05 Adjusted template information in the schematic.
    [eumesmo-poe-4rl-v1.kicad_pcb, eumesmo-poe-4rl-v1.kicad_sch]
